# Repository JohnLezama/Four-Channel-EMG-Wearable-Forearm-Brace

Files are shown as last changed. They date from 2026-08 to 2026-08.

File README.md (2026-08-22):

# Four-Channel EMG Wearable Forearm Brace

<p align="center">
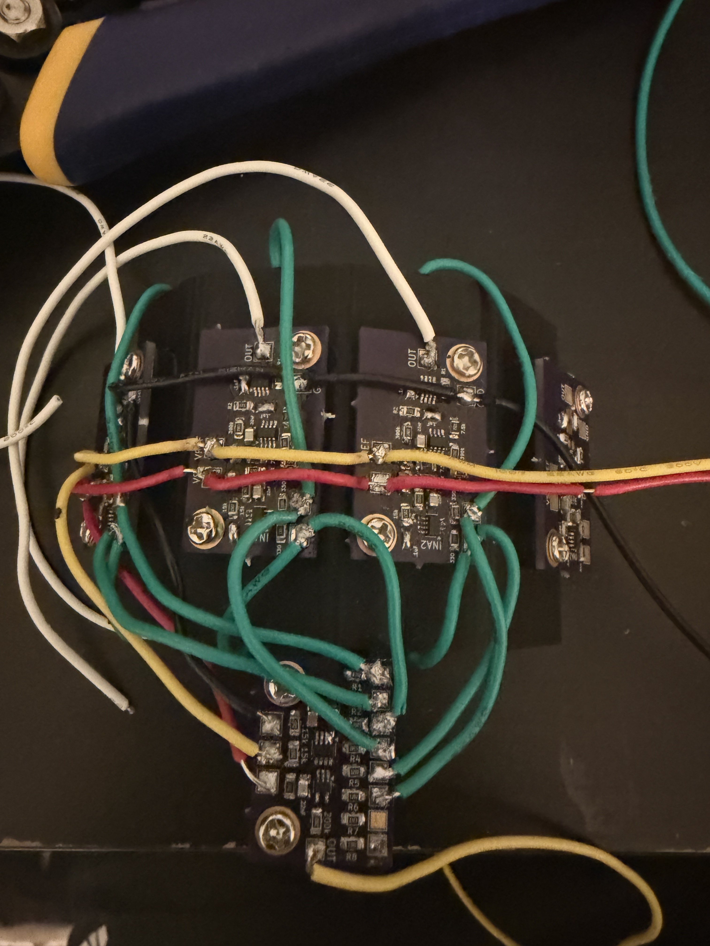
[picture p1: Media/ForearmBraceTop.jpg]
Top view of the EMG forearm brace
  
</p>

**Status:** Functional four-channel acquisition prototype; grip classification and prosthetic control remain in development

**Project period:** Summer 2026

> This is an experimental engineering prototype, not a medical device. It is not intended for diagnosis, treatment, or unsupervised clinical use.

## 1. Project Overview and Current Result

Surface electromyography, or sEMG, measures the electrical activity associated with muscle contraction using electrodes placed on the skin. Many of the muscles responsible for hand movement are located in the forearm, making multi-channel forearm EMG a potential input for grip classification and prosthetic hand control.

The objective of this project was to develop a low-cost wearable system capable of acquiring four forearm EMG channels simultaneously while reducing noise.

I designed and fabricated:

* Four compact analog front-end PCBs
* A separate driven-right-leg feedback and voltage-reference PCB
* A 3D-printed forearm brace that houses:
  * Mounting for eight sensing electrodes and one reference electrode
  * All the PCBs and an ESP32

The current prototype acquires and displays four simultaneous EMG channels with observable responses to finger movements. It establishes the hardware foundation for collecting labeled grip data, training a classification model, and eventually controlling a prosthetic hand in real time.

## 2. Demonstration

https://github.com/user-attachments/assets/97304fc7-ee5d-449a-bffc-9f695163887c

The demonstration shows the completed brace acquiring four EMG channels while different grips are performed.

## 3. System Architecture

```mermaid
flowchart TD
    A["Eight sensing electrodes"] --> B["Four differential electrode pairs"]
    B --> C["Four INA351 instrumentation-amplifier stages"]
    C --> D["20 Hz high-pass filters"]
    D --> E["500 Hz low-pass filters"]
    E --> F["Final gain stages"]
    F --> G["ESP32 ADC inputs"]
    G --> H["Real-time serial visualization"]

    B --> I["Common-mode averaging network"]
    I --> J["Driven-reference and VREF board"]
    J --> K["Reference electrode"]
```

Each EMG channel follows the same analog signal path:

1. Two electrodes measure the differential voltage across a region of the forearm.
2. An INA351 instrumentation amplifier provides an initial gain of 20.
3. A 20 Hz high-pass stage attenuates baseline drift and low-frequency artifacts.
4. A 500 Hz low-pass stage attenuates higher-frequency interference.
5. A final non-inverting stage increases the signal amplitude for acquisition.
6. The output is sampled by the ESP32 and displayed in real time.

A separate board generates a mid-supply voltage reference and implements a driven-right-leg circuit that feeds back to the reference electrode. A resistor network estimates the common-mode component across the electrodes, and the feedback circuit drives the reference electrode to reduce common-mode interference.

## 4. My Contributions

This was an independent project. I was responsible for the complete hardware and software workflow, including:

* Researching surface-EMG acquisition, electrode placement, analog filtering, and driven-reference circuits
* Defining the electrical and mechanical requirements
* Designing and simulating the analog front end in KiCad
* Modeling realistic electrode signals and interference
* Designing the individual EMG-channel PCBs
* Designing the driven-reference and voltage-reference PCB
* Preparing and reviewing PCB fabrication files
* Selecting and soldering the surface-mount components
* Designing the forearm brace in Onshape
* Printing and evaluating electrode-fit prototypes
* Mounting nine electrodes and the associated PCBs
* Wiring the complete wearable system
* Programming the ESP32 in C++ for four-channel acquisition and visualization
* Performing frequency-response and live wearable testing
* Documenting the development and debugging process

https://github.com/user-attachments/assets/0f952d16-c39a-4ed7-ad40-192b02eae874

## 5. Design Requirements

| Requirement | Target | Current Status |
|---|---|---|
| Number of channels | Four simultaneous differential EMG channels | Demonstrated |
| Electrode count | Eight sensing electrodes and one reference electrode | Demonstrated |
| Target passband | Approximately 20–500 Hz | Simulated and bench-tested |
| Initial instrumentation gain | 20× per channel | Implemented |
| PCB size | Maximum of approximately 15 × 20 mm per channel board | Implemented |
| Electrode retention | Secure skin contact during hand movement | Implemented with fitted brace |
| Electrode opening | Fit the selected electrode hardware | Iterated to approximately 4.025 mm |
| Acquisition | Real-time four-channel display | Demonstrated |
| Wearability | Electronics mounted directly on the forearm | Functional prototype |
| Cost | Lower-cost alternative to commercial multi-channel EMG hardware | Final cost not yet calculated |
| Future compatibility | Produce data suitable for grip classification | Dataset and classifier not yet completed |

## 6. Major Design Decisions

### Four modular channel boards

I used four identical signal-conditioning PCBs rather than placing every channel on one large rigid board. This allowed the electronics to be distributed around the forearm, fit the brace geometry, and be tested or replaced one channel at a time.

### Differential instrumentation amplifier

Raw EMG signals are small and are easily overwhelmed by noise. The INA351 instrumentation amplifier was selected to amplify the signal due to its high common-mode rejection ratio.

### 20–500 Hz analog passband

The analog chain uses high-pass and low-pass filtering to retain the primary EMG frequency range while attenuating slow baseline drift, motion artifacts, and higher-frequency noise. Filtering before the ADC also reduces the amount of unwanted signal amplified by later stages.

### Driven-reference feedback

Power-line interference was a major concern because the body and electrode wires can couple environmental noise into every channel. I added a driven-reference circuit based on driven-right-leg topology to estimate the common-mode voltage and feed an inverted correction signal through the reference electrode.

The final board also generates the mid-supply voltage reference required for single-supply analog operation.

### Fixed electrode brace

Surface EMG is highly dependent on electrode position and skin contact. A wearable brace was used to keep the four electrode pairs in consistent locations while also carrying the circuitry.

### Electrode-fit coupon before the full brace

Instead of repeatedly printing the complete brace, I first created a small fitting test containing several electrode-hole diameters. This reduced print time and material use.

### 0805 surface-mount components

The PCBs needed to be small enough to fit the brace but practical enough to solder by hand. The selected component size balanced compactness with solderability.

### ESP32 acquisition

The ESP32 provided multiple ADC channels, C++ programmability, and a path toward future wireless telemetry and real-time prosthetic control.

## 7. Challenges, Failed Approaches, and Fixes

### Driven-reference implementation

**Problem:** I needed to incorporate driven-reference feedback into a four-channel system rather than treating each channel as an isolated circuit.

**Fix:** I designed a separate board that generated VREF and used a resistive averaging network connected to the sensing inputs to estimate the system’s common-mode voltage.

**Result:** The driven-reference circuit could be shared across all four sensing channels and connected to a single reference electrode.

### Electrode-hole sizing

**Problem:** The dimensions taken from the electrode hardware did not directly produce the desired printed fit.

**First approach:** I printed a fitting test with nominal openings of 3.575, 3.650, 3.725, 3.800, 3.875, 3.950, 4.025, and 4.100 mm.

**Fix:** Based on the physical test, I revised the opening to 4.025 mm.

**Result:** The revised geometry produced more secure and repeatable electrode retention in the completed brace.

### PCB area constraint

**Problem:** Each sensing board had to fit within an approximately 15 × 20 mm region of the brace.

**Fix:** I distributed the system across four identical channel boards and a separate driven-reference/VREF board. Component selection occurred after the mechanical envelope had been established.

**Result:** The fabricated electronics could be mounted directly on the wearable structure.

### Fabricated-board debugging

**Problem:** Debugging the complete output alone did not reveal which analog stage was responsible for an unexpected response.

**Fix:** I injected known signals with a function generator and recorded the outputs of the instrumentation-amplifier, filter, and final-gain stages separately. I tested the output at frequencies ranging from 1 Hz to 1 kHz.

**Result:** The node-by-node procedure made it possible to evaluate each stage independently and reveal a burnt chip from the low-pass filter stage.

## 8. Testing and Measurable Results

### Simulation testing

The analog front end was evaluated using:

* AC frequency sweeps
* Transient simulations
* Millivolt-scale differential inputs
* Simulated electrode impedances
* Driven-reference feedback
* A mid-supply voltage reference
* SPICE models for the respective ICs

The simulation demonstrated:

* A stable baseline around the mid-supply reference
* Amplification of the differential input
* Attenuation below the 20 Hz high-pass region
* Attenuation above the 500 Hz low-pass region
* An initial instrumentation-amplifier gain of 20

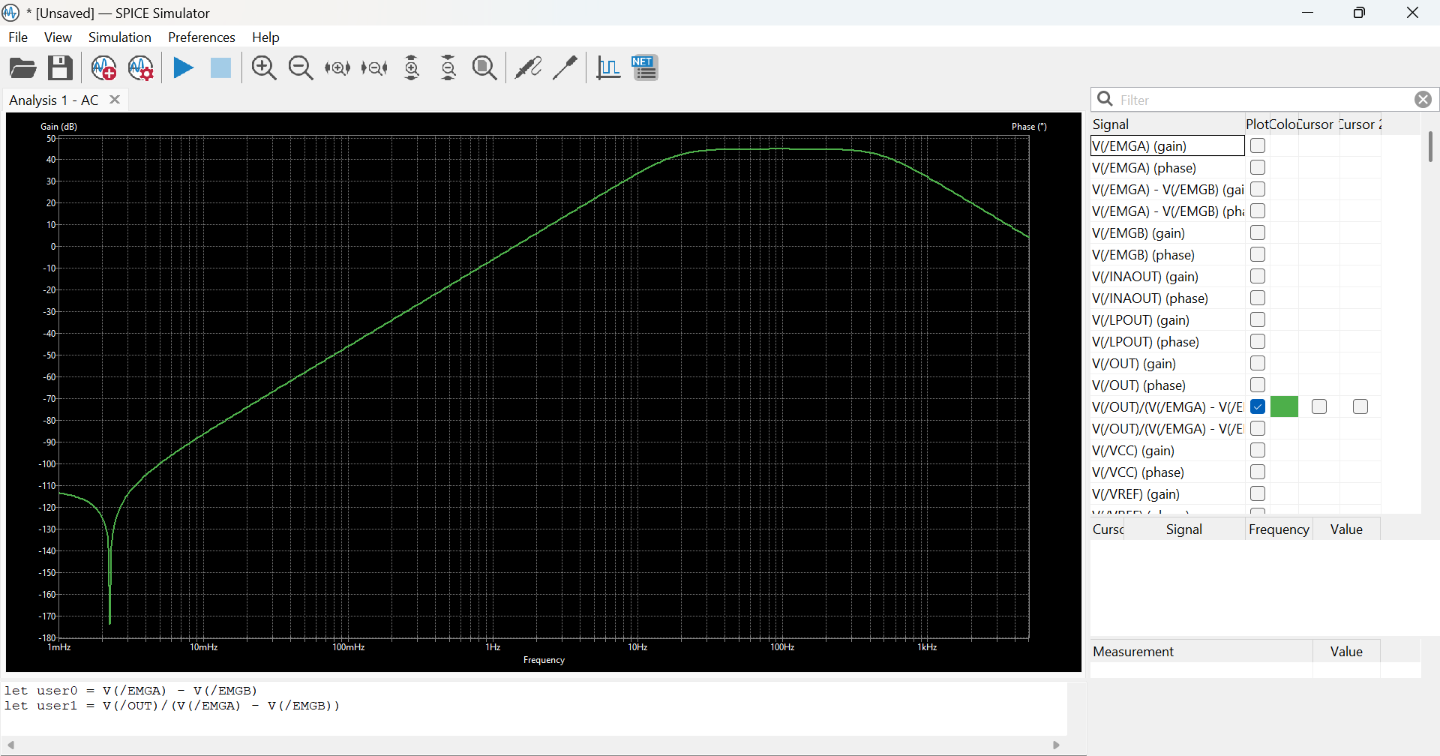
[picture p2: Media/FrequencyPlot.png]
Simulated frequency response


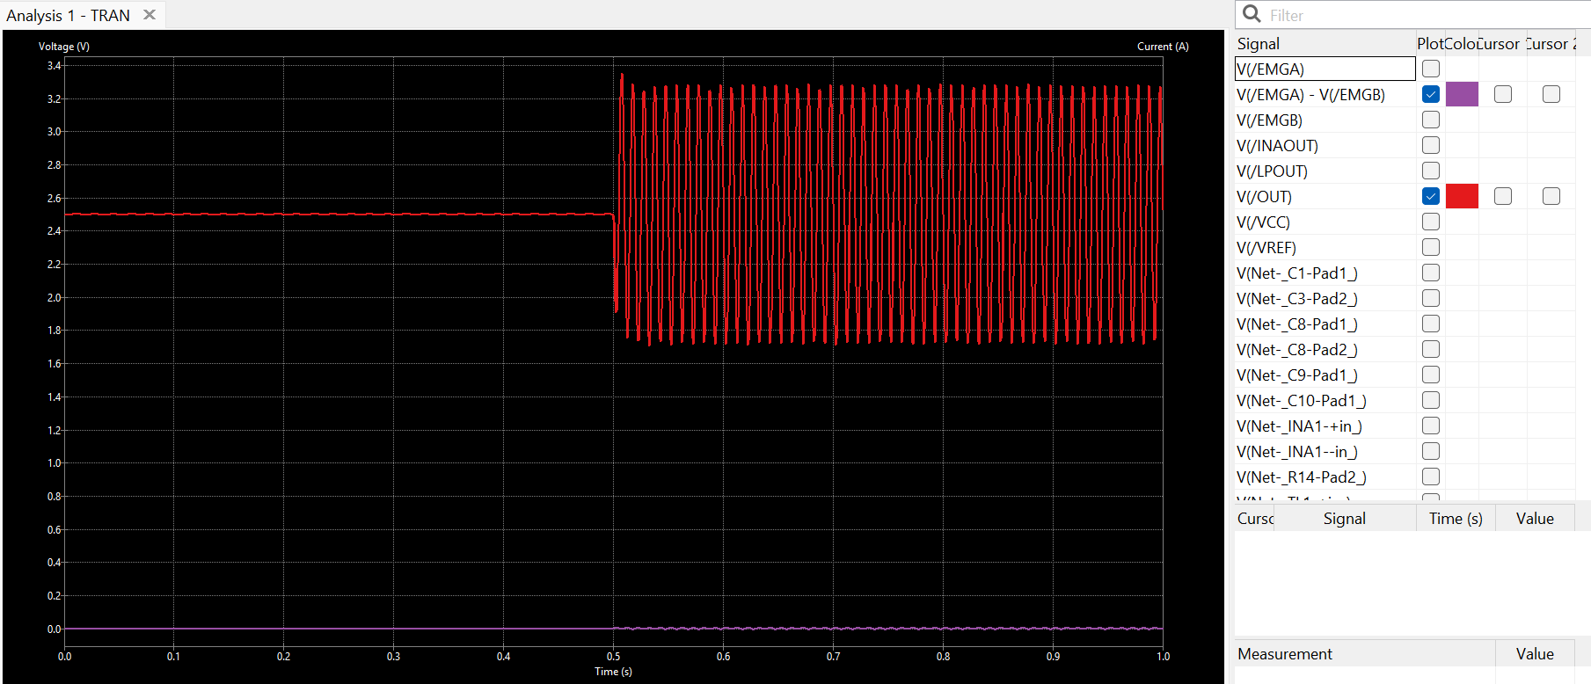
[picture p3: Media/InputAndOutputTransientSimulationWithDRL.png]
Transient EMG simulation


### Bench testing

The fabricated signal board was driven with known test signals at:

`1, 5, 10, 20, 30, 50, 100, 200, 300, 400, 500, 600, 800, and 1000 Hz`

Outputs were captured at the instrumentation-amplifier and final-output nodes. This provided evidence that the fabricated board responded across the intended EMG band and attenuated signals outside it.

### Mechanical testing

| Measurement | Result |
| --- | ---: |
| Sensing channels | 4 |
| Sensing electrodes | 8 |
| Reference electrodes | 1 |
| Total electrodes | 9 |
| Target PCB envelope | 15 × 20 mm per channel |
| Selected electrode opening | Approximately 4.025 mm |

### Wearable demonstration

The completed system displayed four channels simultaneously while finger and hand movements were performed. Each channel showed observable changes during muscle activation.

The current demonstration establishes functional acquisition, but it does not yet provide formal measurements of:

* Signal-to-noise ratio
* Common-mode rejection improvement with and without driven feedback
* Channel crosstalk
* Session-to-session repeatability
* Electrode-placement sensitivity
* ADC accuracy or effective resolution
* Sampling latency
* Grip-classification accuracy

These measurements are planned for the next development phase.

## 9. Repository Guide

```text
Four-Channel-EMG-Wearable-Forearm-Brace/
├── CAD/
│   ├── ForearmBrace - FittingTest.stl
│   └── ForearmBrace.stl
├── Docs/
│   ├── Simulation/
│   │   ├── FrequencyPlot.png
│   │   ├── Input.png
│   │   ├── InputAndOutputTransientSimulationWithDRL.png
│   │   ├── SimulationSetup.png
│   │   ├── TestSchematic.png
│   │   └── VOUT.png
│   ├── Testing/
|   |   ├── FrequencyAmplitudes/
│   │   |   ├── OUT_1000Hz.png
│   │   |   ├── OUT_100Hz.png
│   │   |   ├── OUT_10Hz.png
│   │   |   ├── OUT_1Hz.png
│   │   |   ├── OUT_200Hz.png
│   │   |   ├── OUT_20Hz.png
│   │   |   ├── OUT_300Hz.png
│   │   |   ├── OUT_30Hz.png
│   │   |   ├── OUT_400Hz.png
│   │   |   ├── OUT_500Hz.png
│   │   |   ├── OUT_50Hz.png
│   │   |   ├── OUT_5Hz.png
│   │   |   ├── OUT_600Hz.png
│   │   |   └── OUT_800Hz.png
│   └── parts-list.md
├── Electronics/
│   ├── DRL&VREF/
│   │   ├── PCB/
│   │   |   └── DRL&VREF_V1.zip
│   │   ├── DRL&VREF.kicad_pcb
│   │   ├── DRL&VREF.kicad_pro
│   │   ├── DRL&VREF.kicad_sch
│   │   └── DRL&VREFSchematicScreenshot.png
│   ├── EMG-Channel/
│   │   ├── PCB/
│   │   |   └── EMGPCB_V2.zip
│   │   ├── EMGMain.kicad_pcb
│   │   ├── EMGMain.kicad_pro
│   │   ├── EMGMain.kicad_sch
│   │   └── EMGMainSchematicScreenshot.png
├── Firmware/
|   ├── EMG_SD_Data_Collection.ino
│   └── EMGDemo.ino
├── Media/
│   ├── ForearmBraceTop.jpg
│   ├── FrequencyPlot.png
│   └── InputAndOutputTransientSimulationWithDRL.png
├── README.md
└── References.md
```

### Directory descriptions

- `Firmware/` contains the ESP32 data-acquisition firmware.
- `CAD/` contains the printable brace models.
- `Electronics/` contains the KiCad source files, schematic images, PCB layouts, and Gerber packages.
- `Docs/Simulation/` contains frequency-response and transient-analysis results.
- `Docs/Testing/` contains injected-frequency captures and debugging evidence.
- `Docs/parts-list.md` contains the project bill of materials.
- `Media/` contains the images used in this README.
- `References.md` contains research papers and technical resources consulted during development.

Research papers should be linked or cited rather than redistributed unless their licenses permit redistribution.

## 10. How to Reproduce or Run It

### Safety warning

This is body-connected experimental electronics. Clinical biopotential systems use power and data isolation to limit leakage and ground-loop currents. This prototype has not been evaluated against medical electrical-safety standards.

When electrodes are attached:

* Use an isolated battery power source.
* Do not connect the system to mains-powered bench equipment.
* Disconnect the electrodes before charging, soldering, or probing the circuit.
* Prefer wireless telemetry over a wired connection to a mains-powered computer.
* Do not use the device for diagnosis, treatment, or testing on other people without qualified supervision.

For background on isolation in patient-connected electronics, see Texas Instruments’ [patient-monitor isolation guidance](https://www.ti.com/lit/an/sloa285a/sloa285a.pdf).

### Required hardware

* Four assembled EMG-channel PCBs
* One assembled driven-reference/VREF PCB
* ESP32
* Nine 3M Red Dot 2560 sensing electrodes
* Printed forearm-brace components
* Battery power source: 9V Battery
* Wiring, connectors, and mounting hardware

### Build procedure

1. Fabricate four copies of the EMG-Channel board using `Electronics/EMG-Channel/PCB/EMGPCB_V2.zip`.
2. Fabricate the driven-reference/VREF board using `Electronics/DRL&VREF/PCB/DRL&VREF_V1.zip`.
3. Assemble the PCBs according to the schematics and parts list.
4. Verify power, ground, and VREF before connecting electrodes or the ESP32.
5. Inject a small known test signal and confirm the output of every analog stage.
6. Print the brace from `CAD/`.
7. Install four differential electrode pairs and the reference electrode.
8. Mount the four channel boards and the driven-reference board on the brace.
9. Connect the channel outputs to the selected ESP32 ADC pins.
10. Integrate a compact onboard battery and wireless telemetry for safer, less restrictive wearable testing.11. Upload the code in `Firmware/`.
12. Open the specified serial plotting application and set the baud rate to 9600.
13. Establish a resting baseline before performing hand or finger movements.

The ESP32’s usable ADC range depends on its specific variant and attenuation configuration. Document the final voltage-scaling circuit and verify it against the appropriate [Espressif ADC documentation](https://docs.espressif.com/projects/esp-idf/en/v4.4.7/esp32/api-reference/peripherals/adc.html).

## 11. Current Limitations and Next Steps

Development is currently paused during my transition to UT Austin. I plan to resume the project using university maker-space resources and, if possible, research mentorship.

### Current limitations

* No labeled multi-grip dataset has been collected.
* No classification model has been trained or evaluated.
* Signal-to-noise ratio and common-mode rejection have not been quantified.
* The effect of electrode-position variation has not been measured.
* Testing has primarily been performed on a single user.
* The exposed wiring and separate boards are not yet packaged for long-term wearable use.
* The ESP32 sampling rate, ADC configuration, and voltage scaling need to be formally documented.
* The system has not been evaluated for medical safety or clinical use.
* Total system cost has not yet been calculated.
* Long-session comfort and electrode contact stability have not been evaluated.

### Next steps

1. Finalize the ESP32 acquisition code and document the sampling configuration.
2. Verify ADC input scaling and add protection or an external ADC if necessary.
3. Quantify the noise floor, signal-to-noise ratio, common-mode rejection, and channel crosstalk.
4. Design a repeatable electrode-placement and calibration procedure.
5. Record labeled data for several hand grips across multiple sessions.
6. Establish simple classification baselines before comparing them with a neural network.
7. Evaluate classification accuracy, confusion between grips, and real-time latency.
8. Integrate the classifier with a motorized prosthetic hand.
9. Replace temporary wiring with a more robust harness or consolidated PCB revision.
10. Add battery power and wireless telemetry for safer, less restrictive wearable testing.
11. Evaluate the system across additional users only under appropriate supervision and safety controls.
12. Compare the total cost and performance with existing commercial EMG systems.

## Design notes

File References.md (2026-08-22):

* [Application of EMG feedback for hand prosthesis control in high-level amputation: a case study](https://www.nature.com/articles/s41598-024-80828-x)
* [Finger Motion Decoding Using EMG Signals Corresponding Various Arm Postures](https://pmc.ncbi.nlm.nih.gov/articles/PMC3214794/)
* [The ABC of EMG](https://www.academia.edu/7419094/ABC_of_EMG)

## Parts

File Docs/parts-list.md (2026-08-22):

* sEMG Electrodes - [Link](https://www.amazon.com/3m-Red-Dot-Monitoring-Electrode/dp/B0015TI4G2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)
* (20) 22 nF capacitors - [Link](https://www.mouser.com/en/ProductDetail/Murata-Electronics/GCM21B5C1H223FA16L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)
* (1) 595-OPA333AIDCKR IC [Link](https://www.mouser.com/en/ProductDetail/Texas-Instruments/OPA333AIDCKR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)
* (9) 595-OPA2375IDDFR IC [Link](https://www.mouser.com/en/ProductDetail/Texas-Instruments/OPA2375IDDFR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)
* (4) INA351ABSIDDFR IC [Link](https://www.mouser.com/en/ProductDetail/Texas-Instruments/INA351ABSIDDFR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)
* SMD Resistor Kit - [Link](https://www.amazon.com/Chanzon-Resistor-Tolerance-Resistors-Certificated/dp/B08RYMY6XK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)

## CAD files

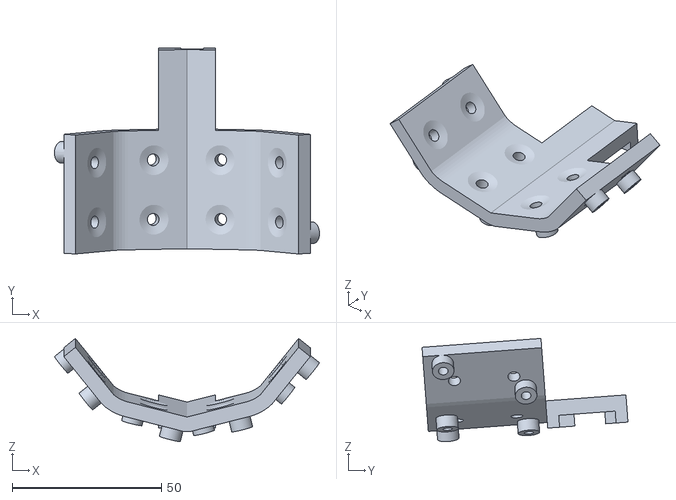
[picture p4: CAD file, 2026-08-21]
CAD/ForearmBrace.stl
88.9 x 69.1 x 34.6

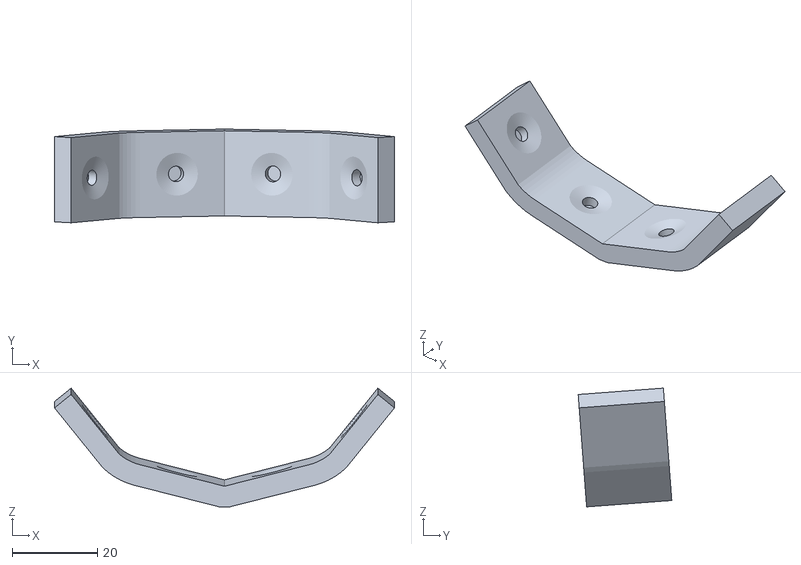
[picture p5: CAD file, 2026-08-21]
CAD/ForearmBrace - FittingTest.stl
79.6 x 21.9 x 27.8

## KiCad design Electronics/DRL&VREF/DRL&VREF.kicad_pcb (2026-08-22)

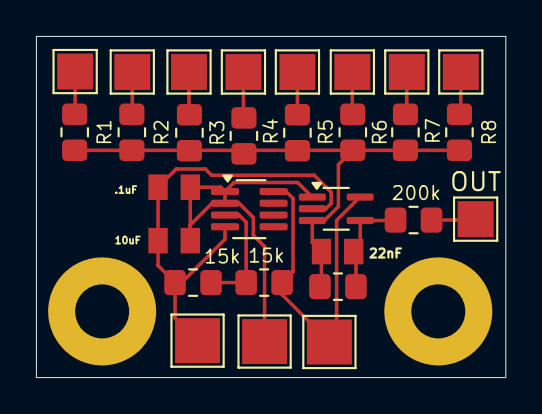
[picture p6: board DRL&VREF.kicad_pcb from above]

Board: 2 copper layers, 26.1 x 18.9 mm, 29 parts (0 on the bottom side), 15 nets.

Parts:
10uF, 22nF, .1uF: c=GCM21B5C1H223FA16L; CAPC2012X140N
15k, 15k#2: 15k; R_0805_2012Metric_Pad1.20x1.40mm_HandSolder
200k: 200k; R_0805_2012Metric_Pad1.20x1.40mm_HandSolder
E1, E2, E3, E4: Conn_01x01_Pin; TestPoint_Pad_2.0x2.0mm
E'1, E'2, E'3, E'4: Conn_01x01_Pin; TestPoint_Pad_2.0x2.0mm
GND: Conn_01x01_Pin; TestPoint_Pad_2.5x2.5mm
OUT: Conn_01x01_Pin; TestPoint_Pad_2.0x2.0mm
R1, R2, R3, R4, R5, R6, R7, R8: 12k; R_0805_2012Metric_Pad1.20x1.40mm_HandSolder
R10: 75k; R_0805_2012Metric_Pad1.20x1.40mm_HandSolder
U1: OPA333xxDCK; SOT-353_SC-70-5_Handsoldering
U2: TL072; SOT-23-8_Handsoldering
VREF: Conn_01x01_Pin; TestPoint_Pad_2.5x2.5mm
VS: Conn_01x01_Pin; TestPoint_Pad_2.5x2.5mm

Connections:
unnamed: 22nF.2, 200k.2, R10.1, U1.4
unnamed: E1.1, R1.1
unnamed: E2.1, R3.1
unnamed: E3.1, R5.1
unnamed: E4.1, R7.1
unnamed: E'1.1, R2.1
unnamed: E'2.1, R4.1
unnamed: E'3.1, R6.1
unnamed: E'4.1, R8.1
unnamed: 10uF.2, 15k.2, .1uF.2, GND.1, U1.2 (V-), U2.4 (V-)
unnamed: 200k.1, OUT.1
unnamed: 10uF.1, .1uF.1, U1.1 (+), U2.1, U2.2 (-), VREF.1
unnamed: 22nF.1, R1.2, R2.2, R3.2, R4.2, R5.2, R6.2, R7.2, R8.2, R10.2, U1.3 (-)
unnamed: 15k#2.1, U1.5 (V+), U2.8 (V+), VS.1
unnamed: 15k.1, 15k#2.2, U2.3 (+)

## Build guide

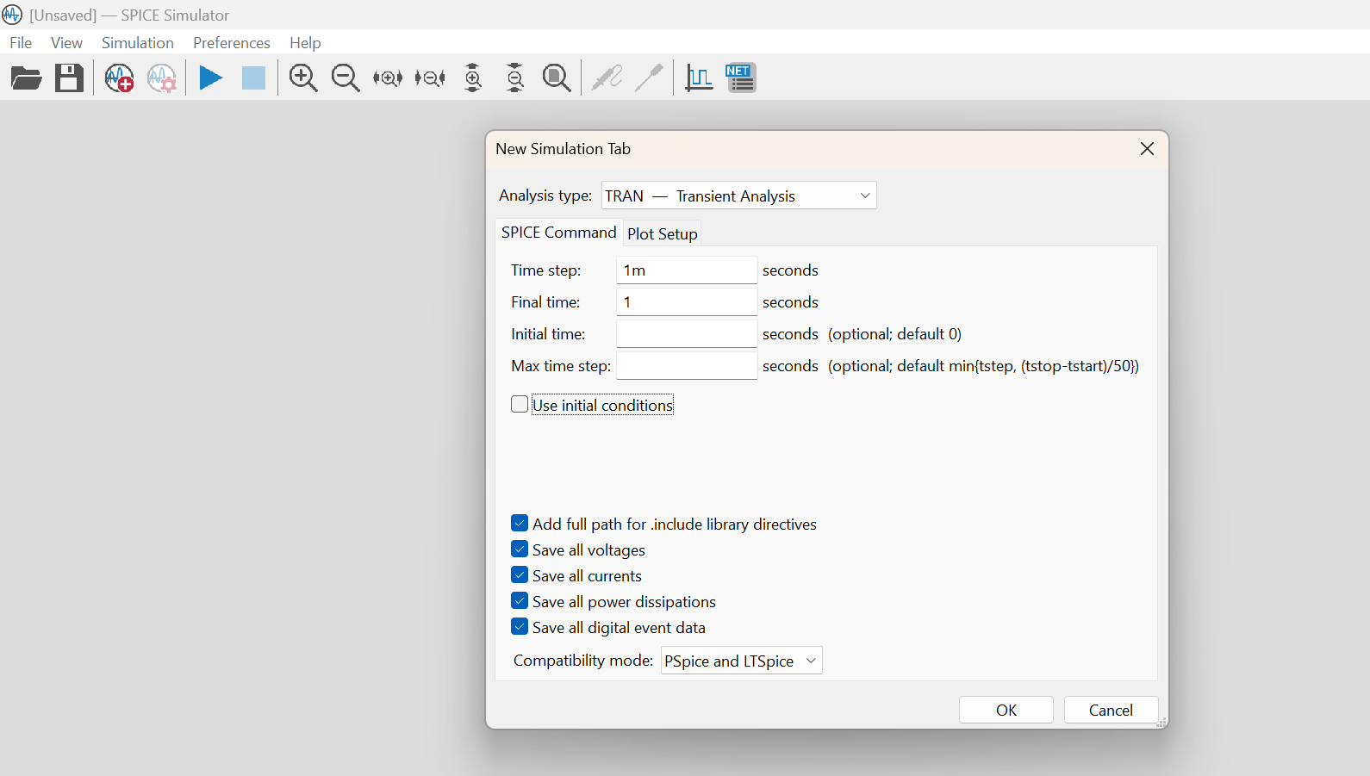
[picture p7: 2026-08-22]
Docs/Simulation/SimulationSetup.png

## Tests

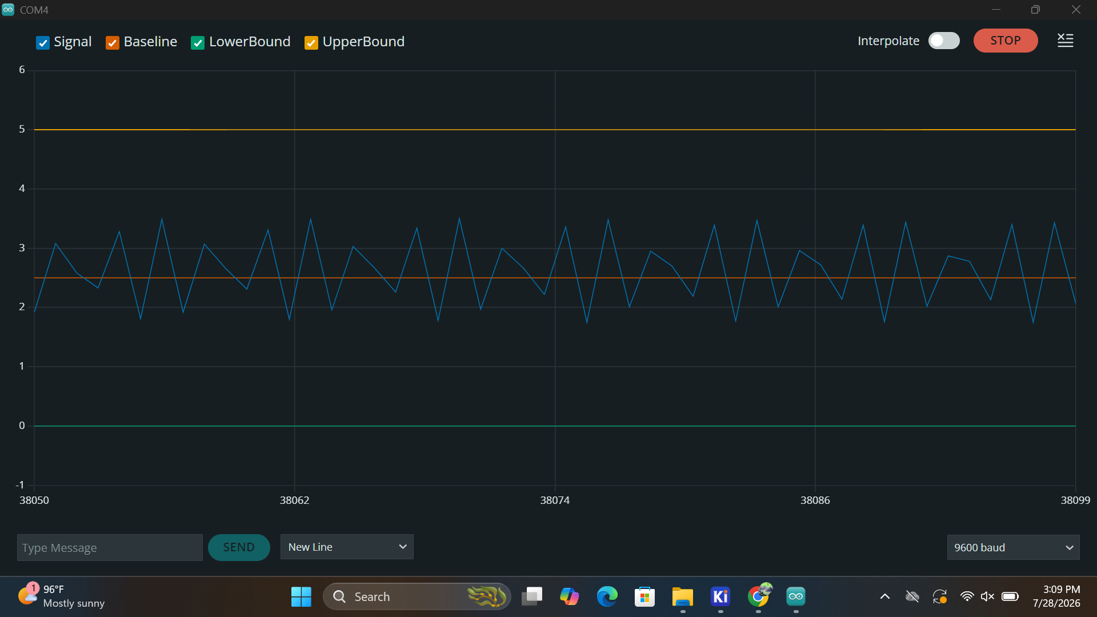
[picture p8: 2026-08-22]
Docs/Testing/FrequencyAmplitudes/OUT_600Hz.png

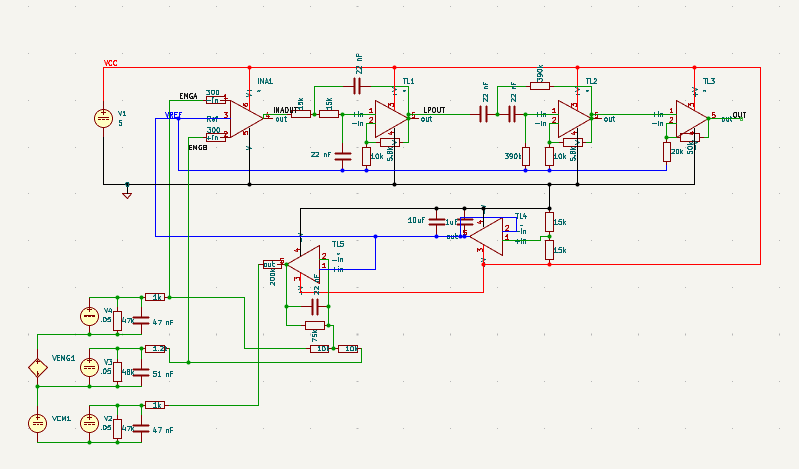
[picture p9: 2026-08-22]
Docs/Simulation/TestSchematic.png

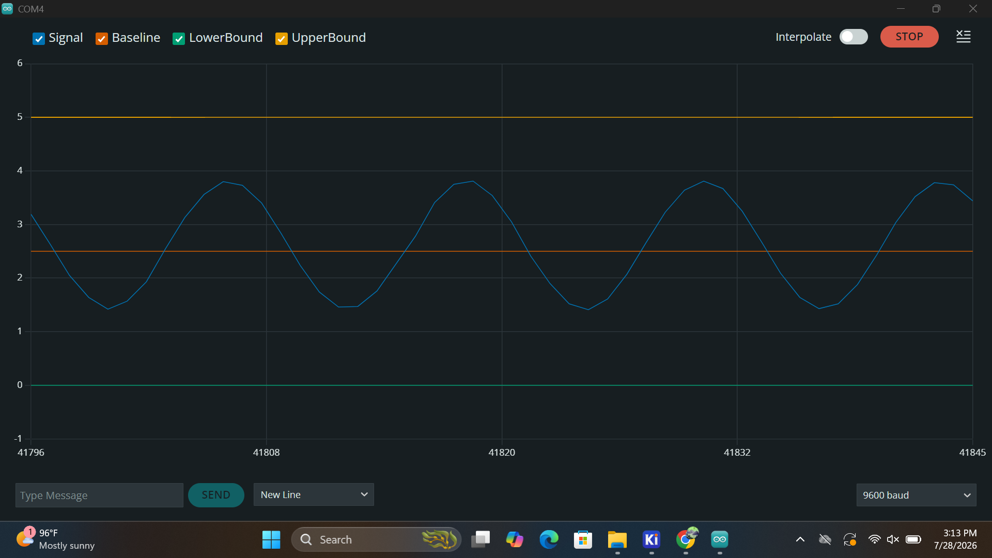
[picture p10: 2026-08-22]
Docs/Testing/FrequencyAmplitudes/OUT_20Hz.png

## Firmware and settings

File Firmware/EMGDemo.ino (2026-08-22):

void setup() {
  Serial.begin(9600);
}

void loop() {
  Serial.println("Reference:1.65");
  Serial.print("Channel1:");
  Serial.println(analogRead(32)*3.3/4095);  
  Serial.print("Channel2:");
  Serial.println(analogRead(33)*3.3/4095);  
  Serial.print("Channel3:");
  Serial.println(analogRead(34)*3.3/4095);  
  Serial.print("Channel4:");
  Serial.println(analogRead(35)*3.3/4095);  
}

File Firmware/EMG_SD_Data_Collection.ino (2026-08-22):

#include <SPI.h>
#include <SD.h>

unsigned long prev;
unsigned long start;
const unsigned long interval = 500;
const unsigned long limit = 2000000/interval;
int CS_PIN = 5;

struct Sample{
  int count;
  unsigned long time;
  int in1;
  int in2;
  int in3;
  int in4;
};

Sample* samples = nullptr;


void setup() {
  Serial.begin(9600);
  delay(5000);
  Serial.println("Initializing SD Card");
  SPI.begin(18, 19, 23, 5);
  if(!SD.begin(CS_PIN, SPI, 1000000)){
    Serial.println("SD initialization failed.");
     while(true);
  }
  for(int sampleCount = 1; sampleCount<=10; sampleCount++){
    String grips[] = {"A", "B", "C", "D", "E", "F", "G", "H", "I", "J", "K", "L", "M", "N"};
    for(String s: grips){
      samples = new Sample[limit];
      Serial.println("Commencing data collection for " + s + String(sampleCount) + " grip in 3");
      delay(1000);
      Serial.println("2");
      delay(1000);
      Serial.println("1");
      delay(1000);
      Serial.println("RECORDING...");
      
      start = micros();
      prev = start;
      int count = 0;
      while(count<limit){
        unsigned long curr = micros();
        if(curr-prev>=interval){
          prev+=interval;
          samples[count].count = count;      
          samples[count].time = curr-start; 
          samples[count].in1 = analogRead(32);
          samples[count].in2 = analogRead(33);
          samples[count].in3 = analogRead(34);
          samples[count].in4 = analogRead(35);
          count++;
        }
      }
      Serial.println("Writing Data to SD Card...");
      File dataFile = SD.open("/"+s+String(sampleCount)+".csv", FILE_WRITE);
      if(dataFile){
        for(int i = 0; i<limit; i++){
          dataFile.print(samples[i].count);     dataFile.print(",");
          dataFile.print(samples[i].time);      dataFile.print(",");
          dataFile.print(samples[i].in1*3.3/4095);       dataFile.print(",");
          dataFile.print(samples[i].in2*3.3/4095);       dataFile.print(",");
          dataFile.print(samples[i].in3*3.3/4095);       dataFile.print(",");
          dataFile.println(samples[i].in4*3.3/4095);     
        }
        dataFile.close(); 
        Serial.println("Data successfully written to SD card!");
      }
      else {
          Serial.println("Error opening data.csv for writing!");
      }
      delete[] samples;
    }
  }
}

void loop() {

}
